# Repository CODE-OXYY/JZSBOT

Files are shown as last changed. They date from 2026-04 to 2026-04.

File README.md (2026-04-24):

# JZSBOT (Desktop Pet Robot)
I built a custom desktop robot with the personality of my favorite streamer, including audio and animation which are stored in sd card. It was built entirely from scratch, I designed both the custom electronics (PCB) and the physical 3D body (CAD) it can move with the help of two N20 motors, show animations on a 3.5 inch display which is the face of the robot, and play sound with the help of a 3 ohm 4 watt speaker. This robot has built in environment, gyro, and other sensors.

## 🛠️ Hardware & PCB Design
The schematic was designed in Altium, split into 3 sheets for better readability.

### Schematics
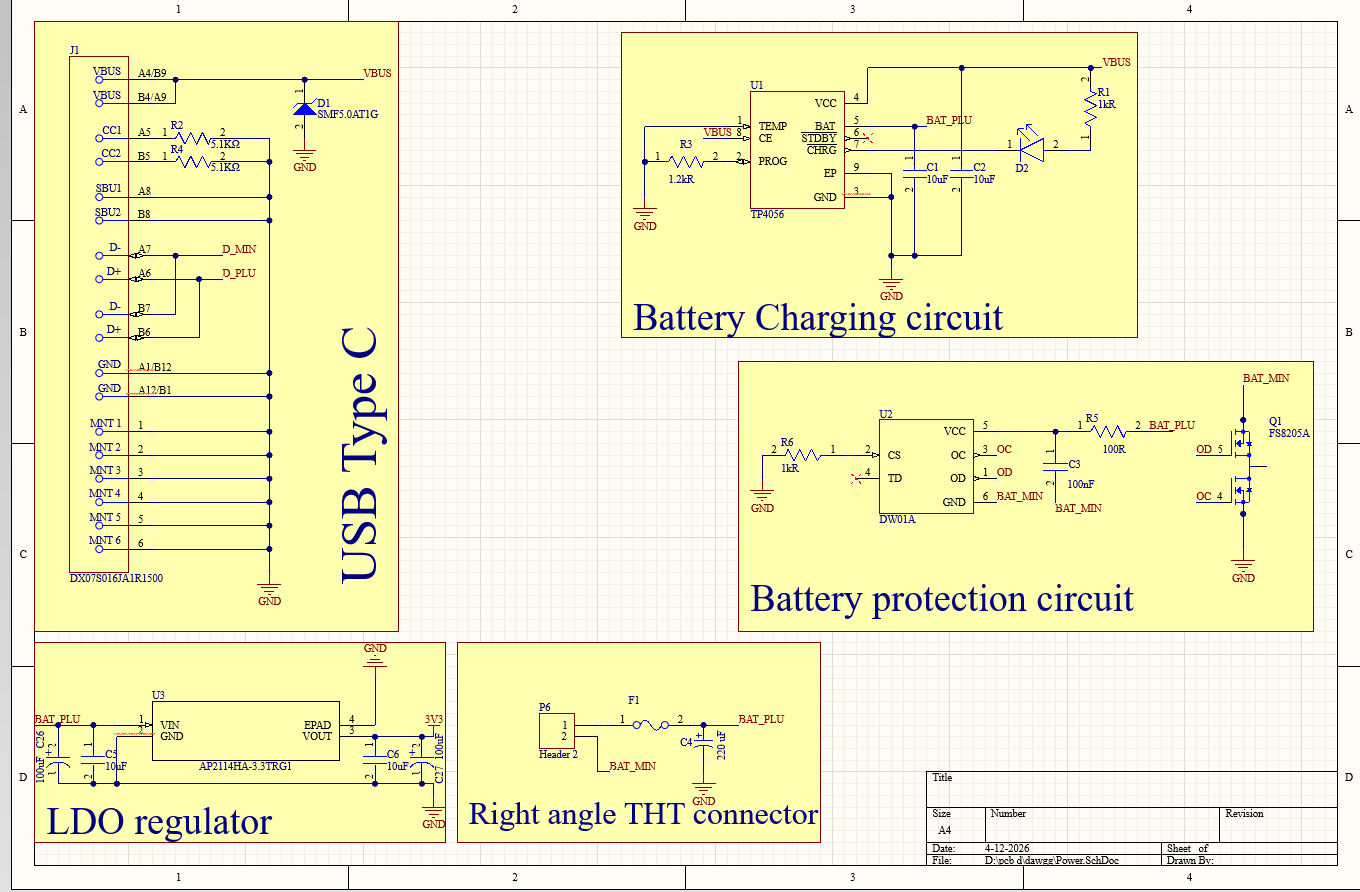
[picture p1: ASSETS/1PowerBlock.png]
Power Section

*Sheet 1: Power Section*

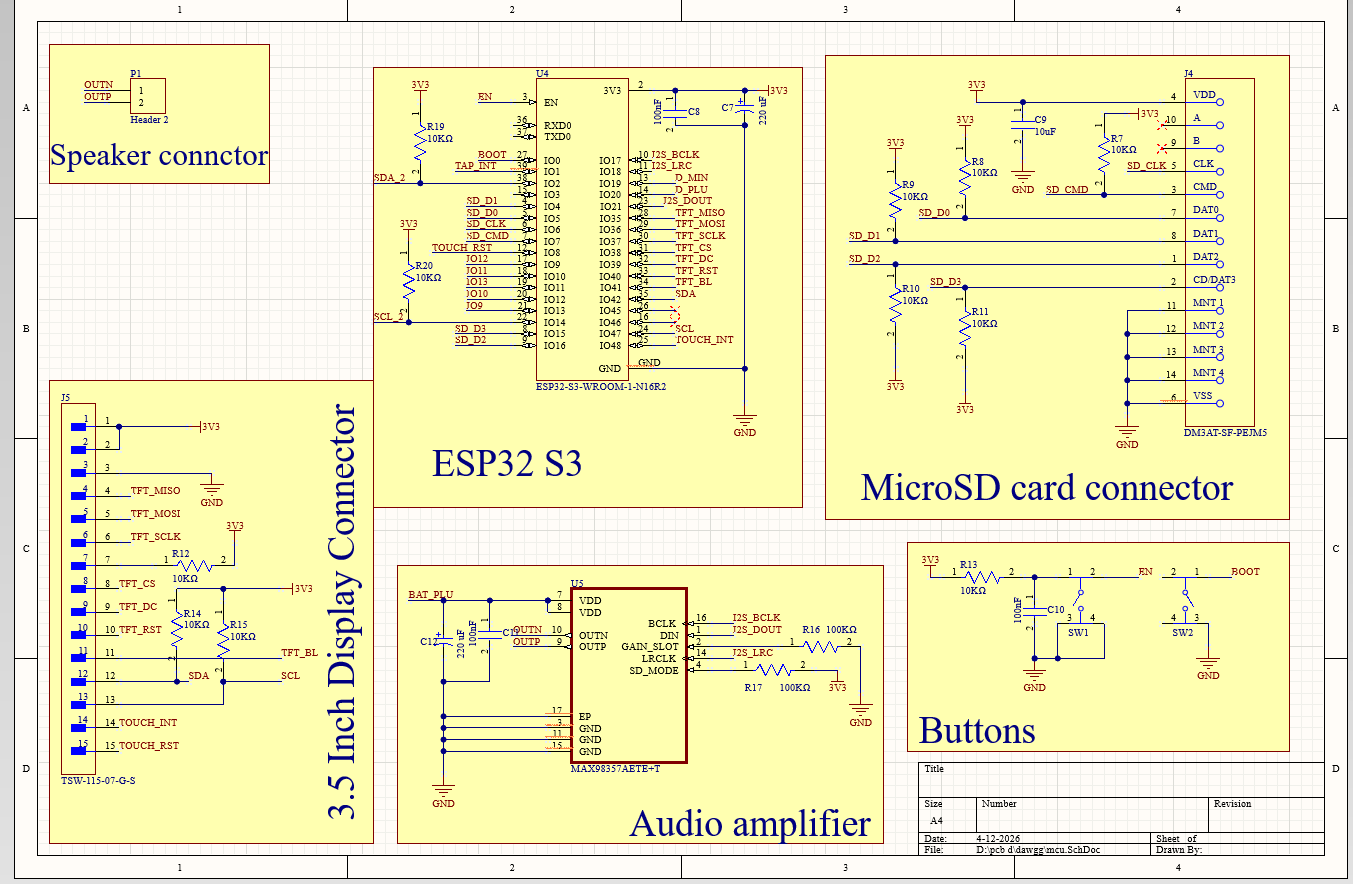
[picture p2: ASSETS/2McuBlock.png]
MCU Section

*Sheet 2: MCU Section*

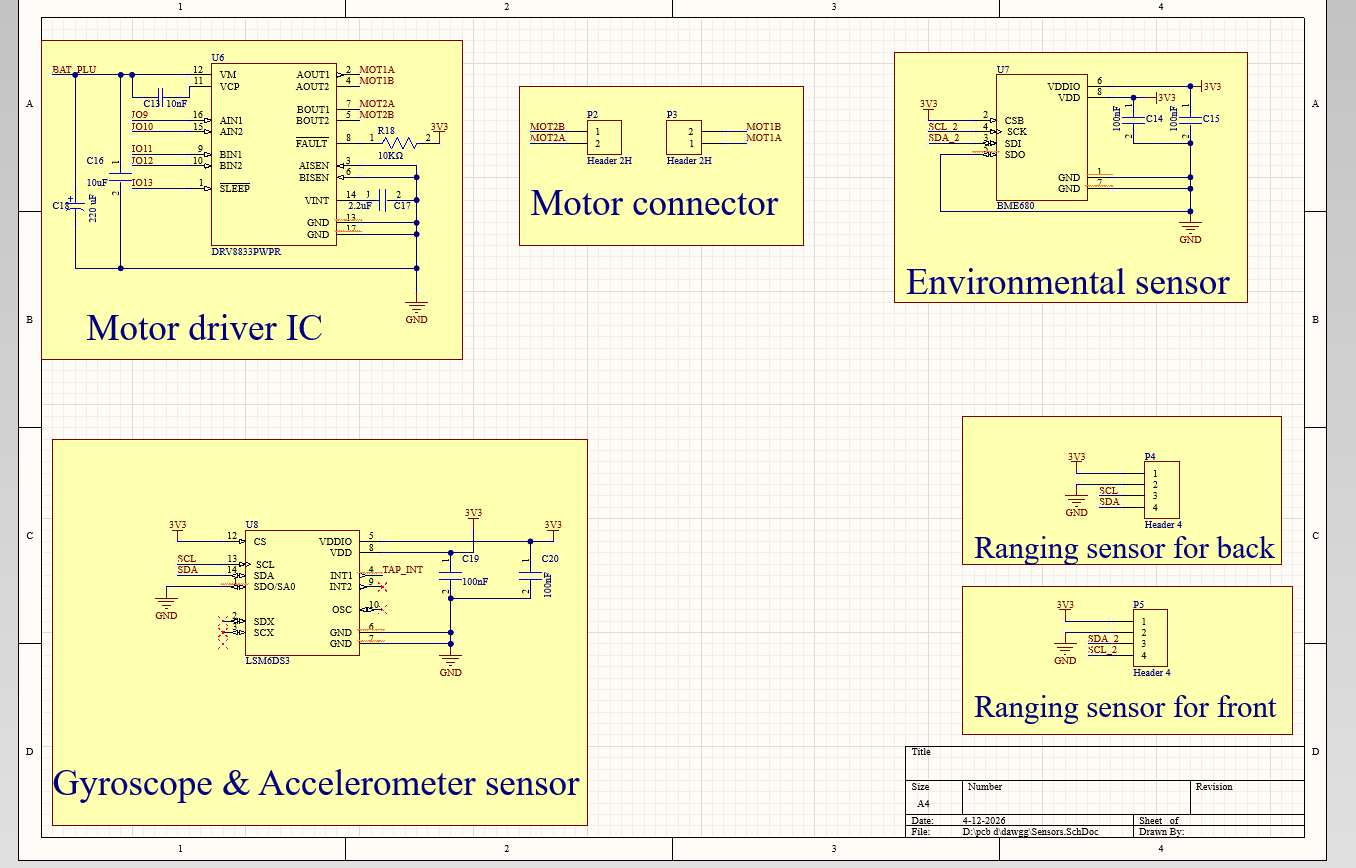
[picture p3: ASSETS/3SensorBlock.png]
Sensor Section

*Sheet 3: Sensor Section*

### PCB Layout
Designed at a precise 84mm x 83mm, keeping it under the cheap 100x100mm manufacturing threshold.
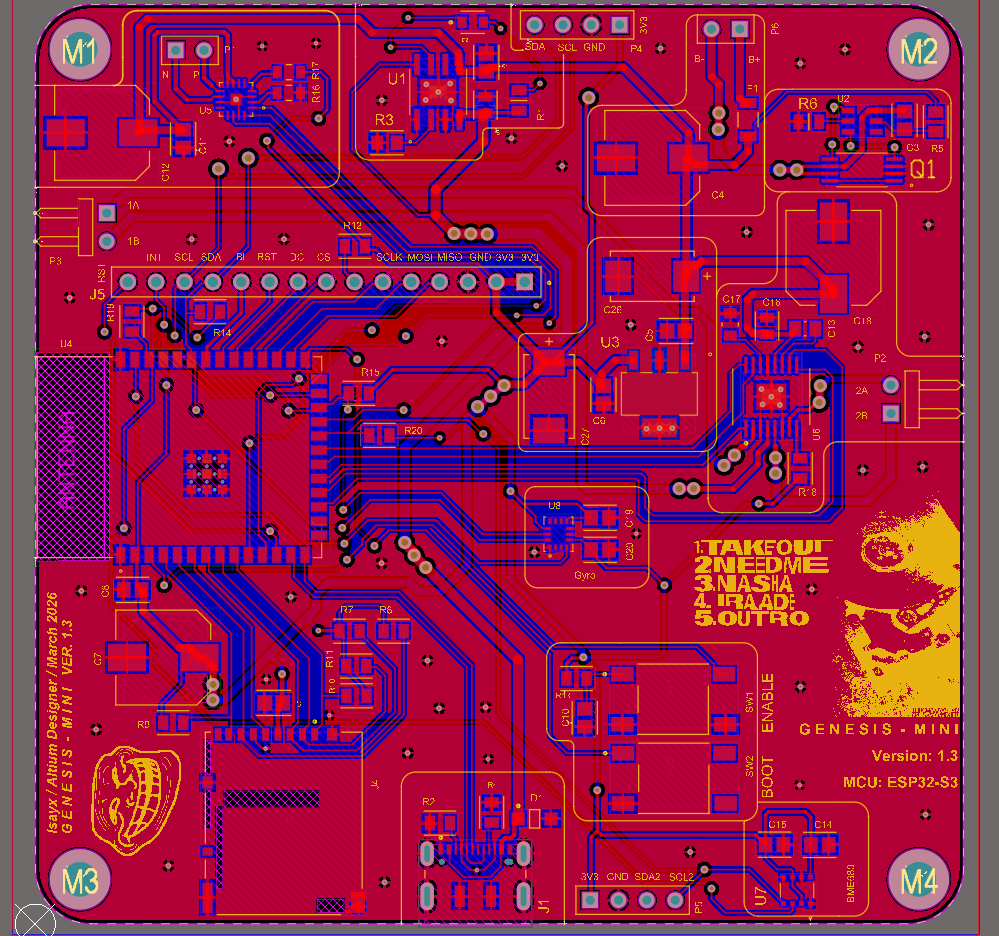
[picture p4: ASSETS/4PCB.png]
PCB Layout


### PCB 3D View
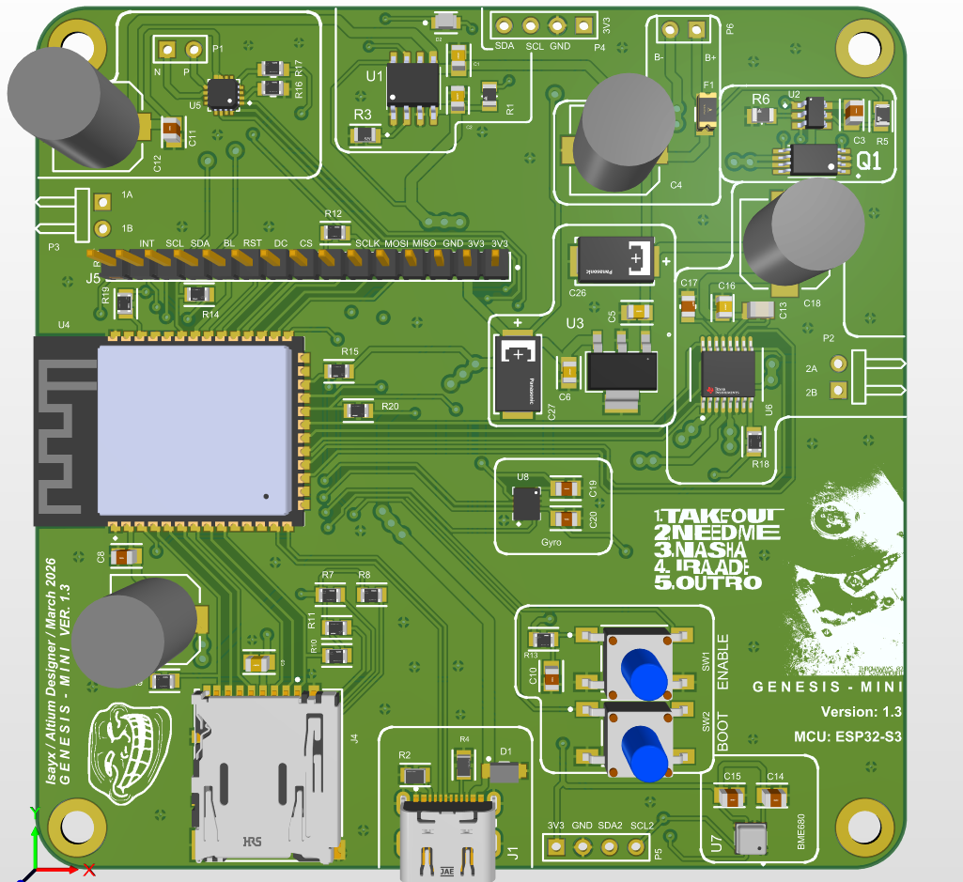
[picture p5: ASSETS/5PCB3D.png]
PCB 3D


---

## 📦 Mechanical Design (Body)
The custom enclosure was modeled in **Onshape** and is split into 4 main 3D printable parts.
🔗 **[View 3D Model on Onshape](https://cad.onshape.com/documents/115dd9a062e470791892991f/w/46b9cbcaef62df69c897060a/e/b46bb490fd50a7f6dd43c250)**

### Head Cap
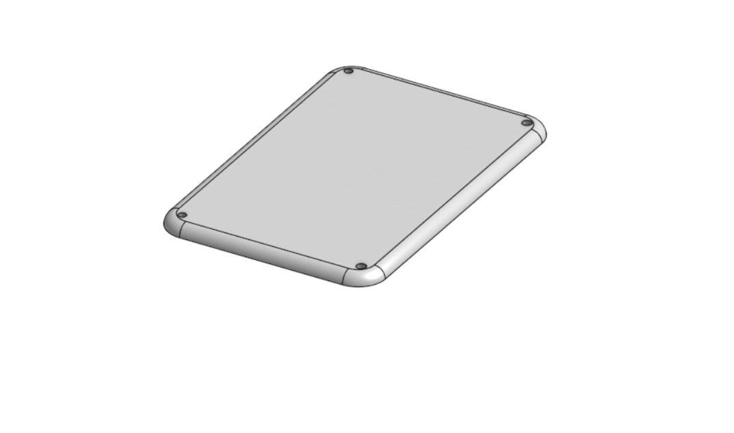
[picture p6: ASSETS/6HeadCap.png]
Head Cap


### Head
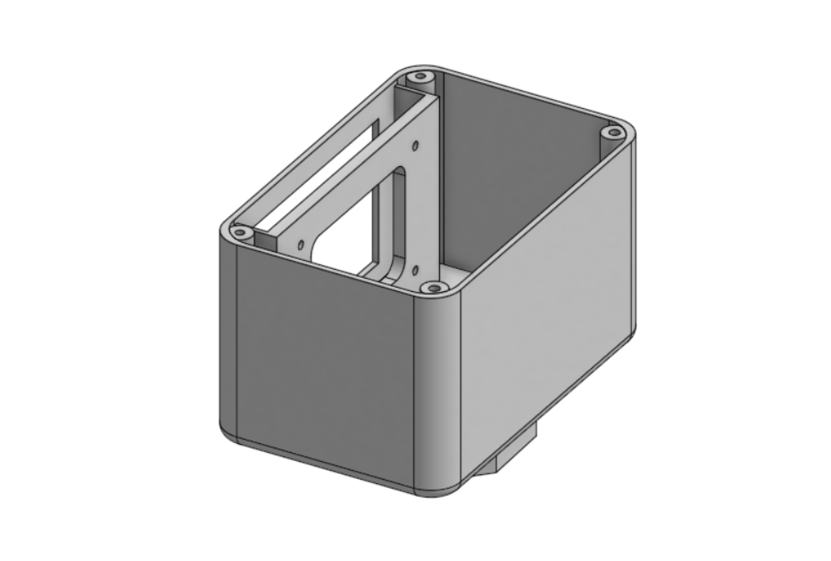
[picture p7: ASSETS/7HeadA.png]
Head A

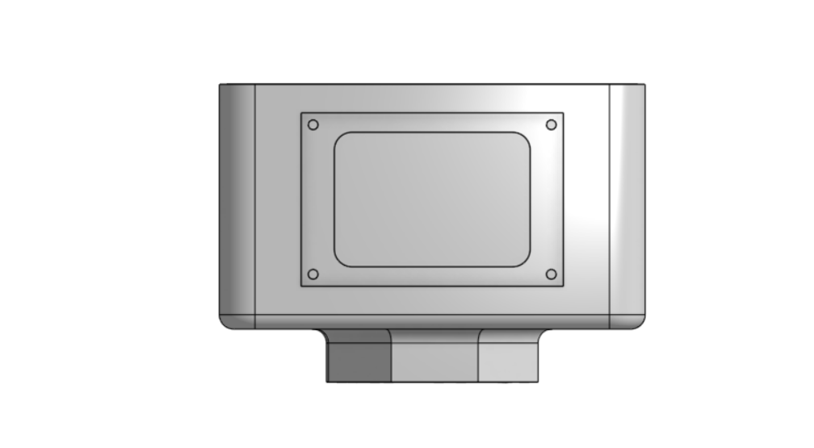
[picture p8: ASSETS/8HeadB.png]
Head B


### Walls
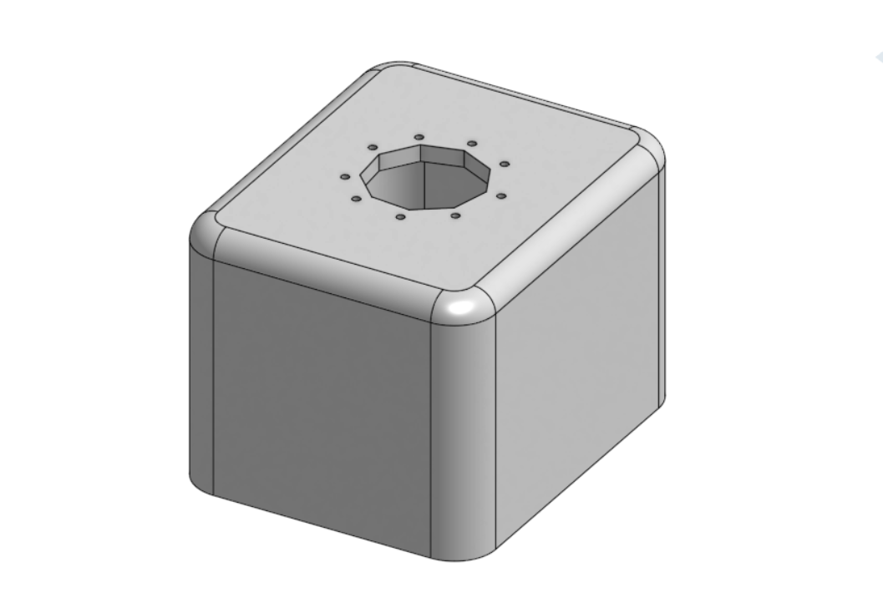
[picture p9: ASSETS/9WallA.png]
Wall A

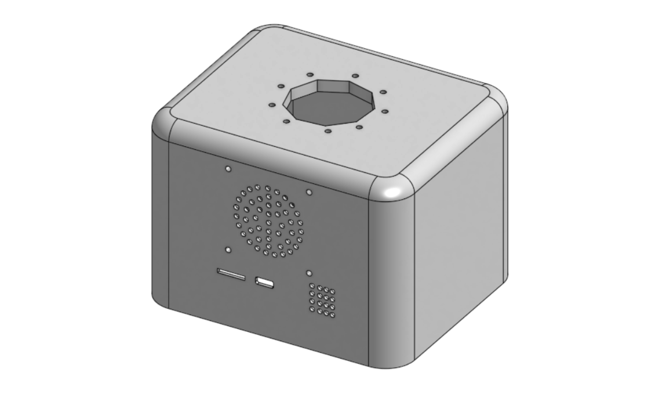
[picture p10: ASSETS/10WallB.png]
Wall B


### Base
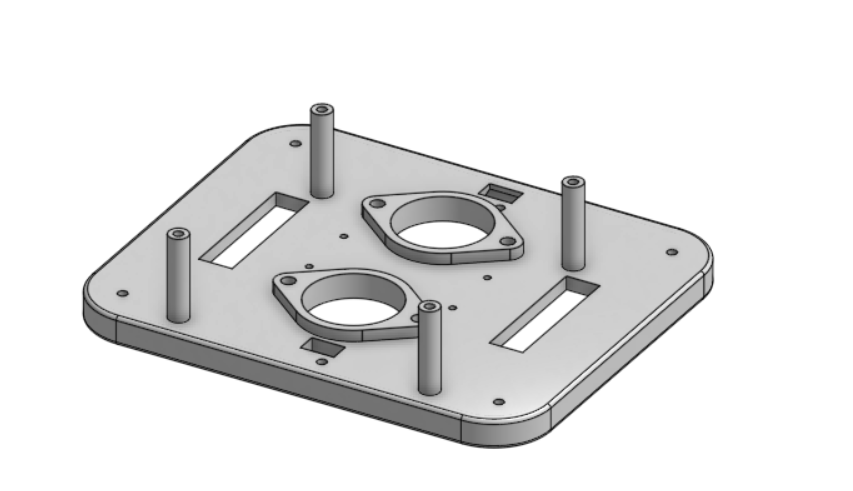
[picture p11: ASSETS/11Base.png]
Base

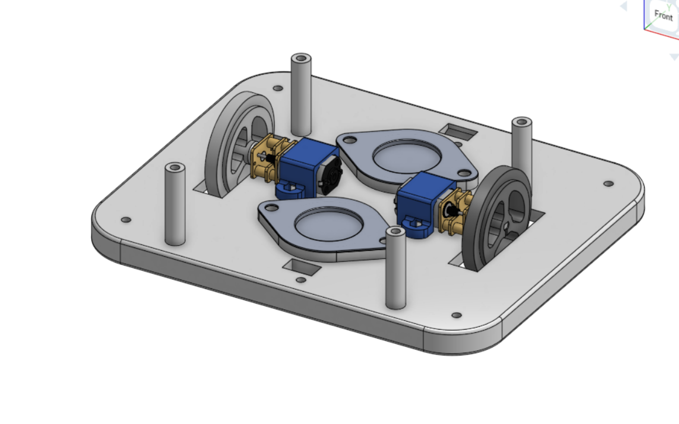
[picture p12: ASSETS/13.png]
Base Details


### Assembly
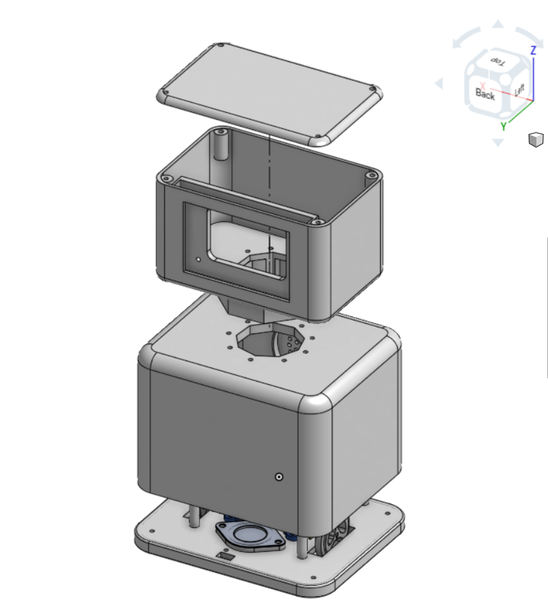
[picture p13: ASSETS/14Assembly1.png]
JZSBOT Assembly 1

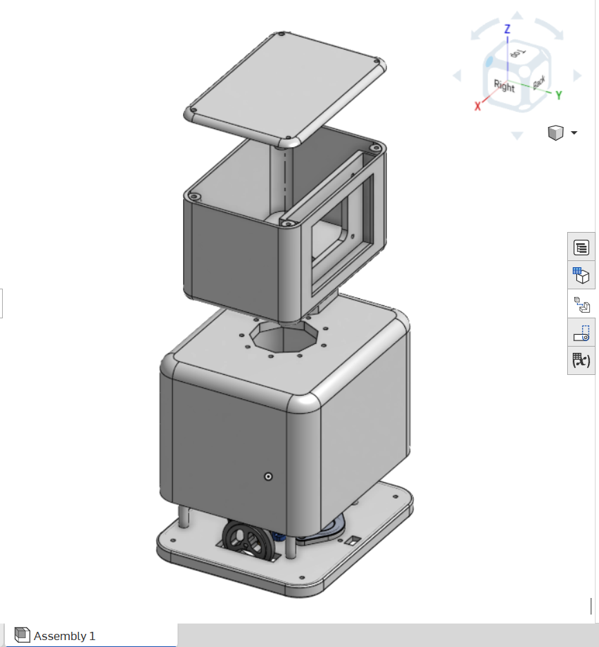
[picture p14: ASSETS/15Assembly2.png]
JZSBOT Assembly 2

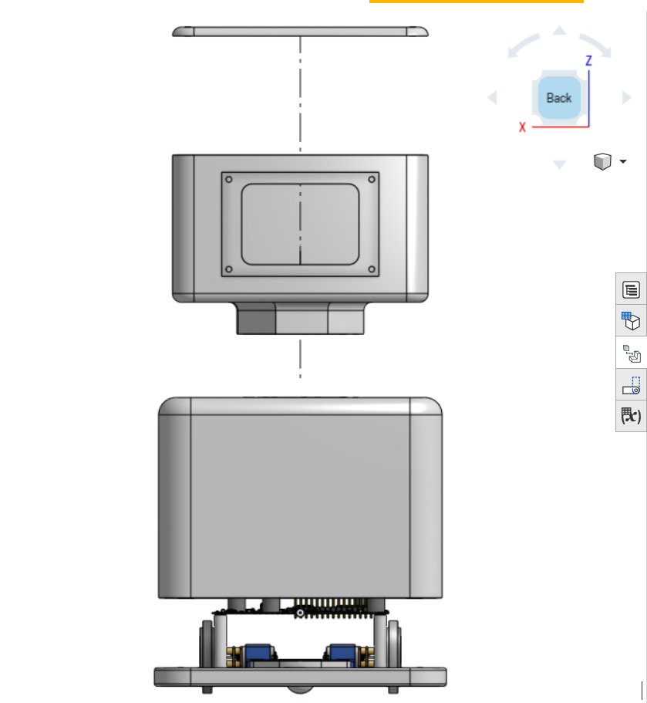
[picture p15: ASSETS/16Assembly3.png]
JZSBOT Assembly 3

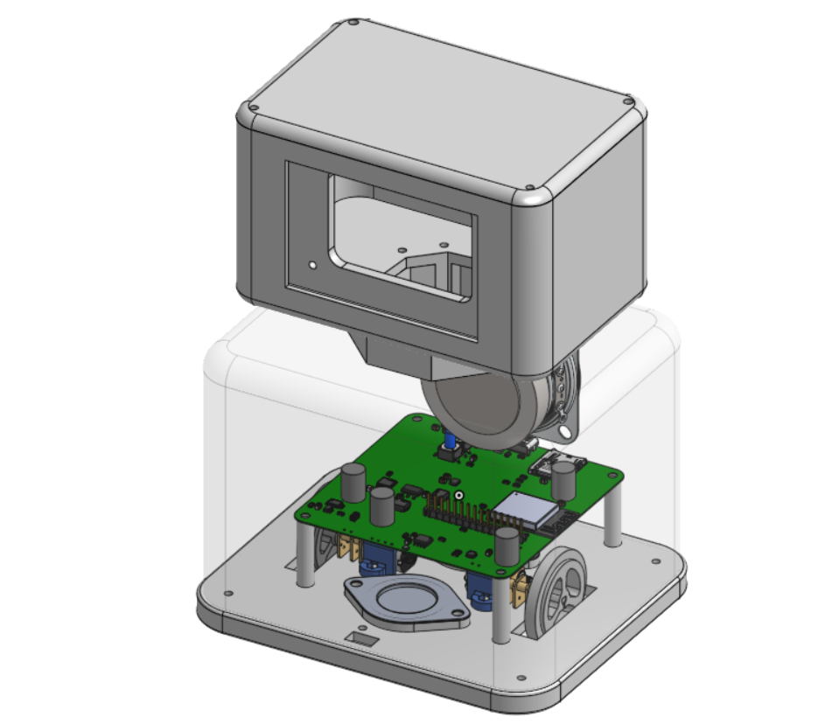
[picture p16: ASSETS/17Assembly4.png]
JZSBOT Assembly 4

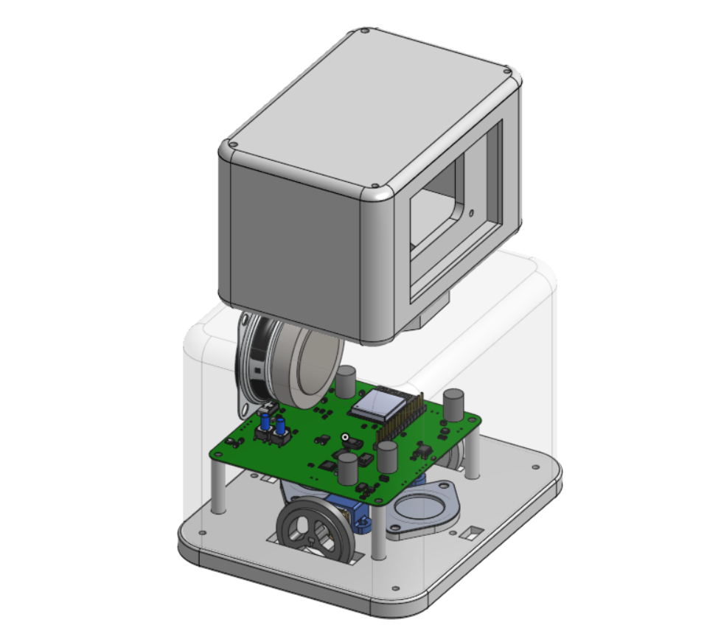
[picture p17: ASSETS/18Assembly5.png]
JZSBOT Assembly 5

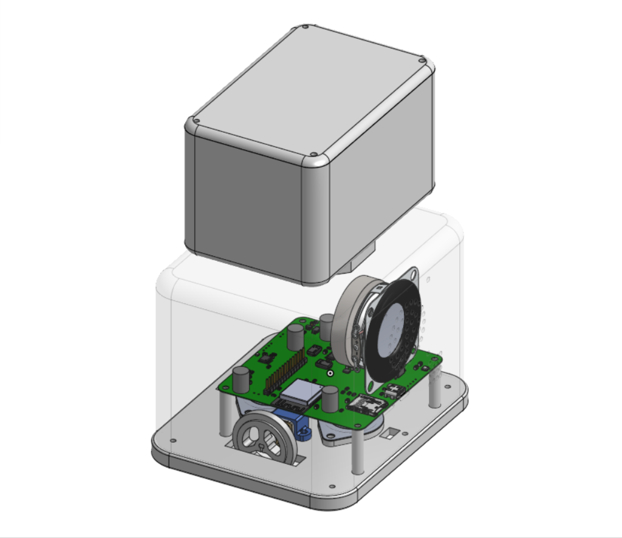
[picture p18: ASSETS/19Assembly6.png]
JZSBOT Assembly 6


### Fully Assembled JZSBOT
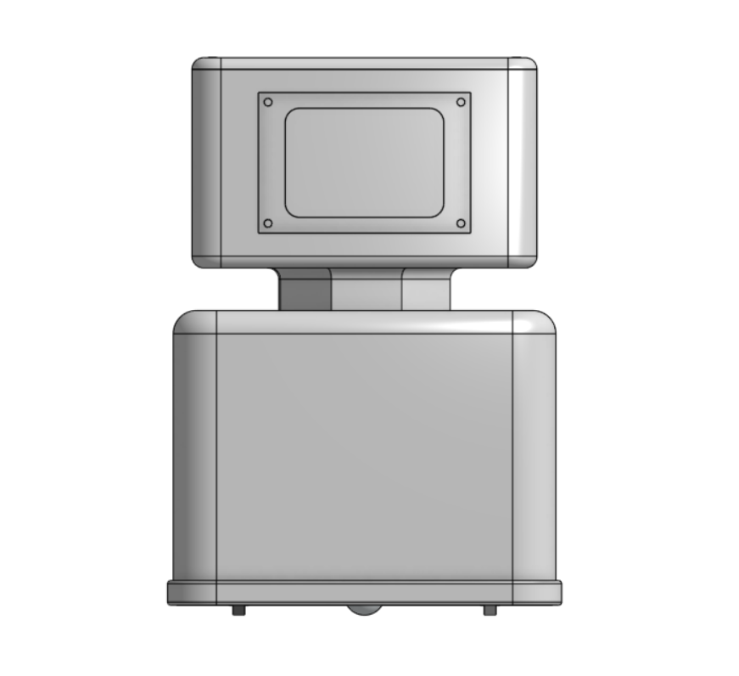
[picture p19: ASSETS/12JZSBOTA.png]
JZSBOT Assembled A

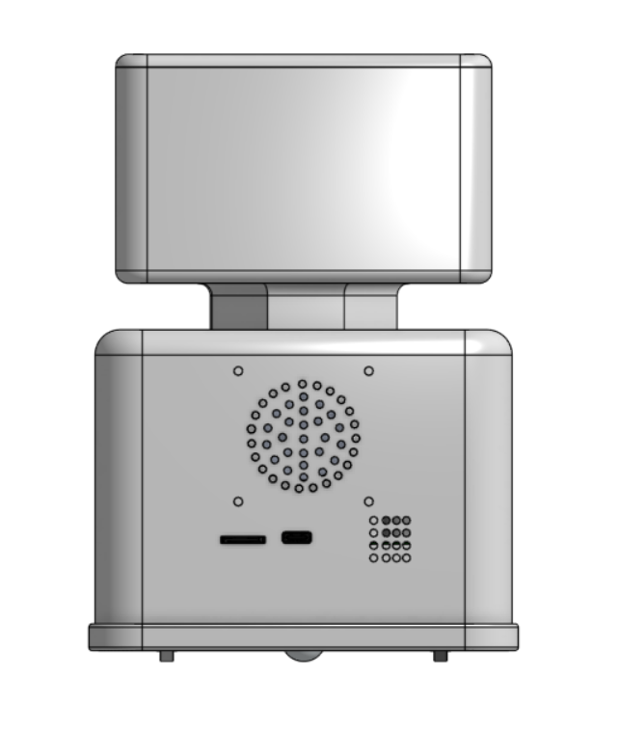
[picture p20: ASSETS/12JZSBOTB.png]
JZSBOT Assembled B

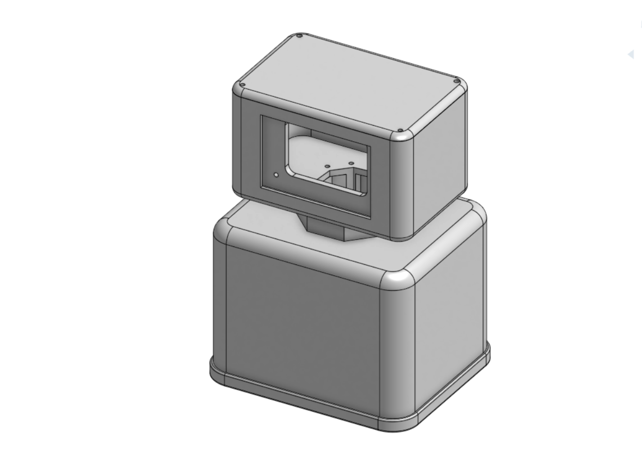
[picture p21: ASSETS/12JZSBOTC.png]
JZSBOT Assembled C


---

## ✨ Features
* **Brain:** ESP32-S3
* **Face:** 3.5" Waveshare Capacitive Touch Display
* **Audio:** On-board 4 ohm 3W speaker for personality sounds
* **Sensors:** BME680 (Environment), LSM6DS3 (Accelerometer & Gyroscopes) and VL53L0X (Distance)
* **Movement:** 2x N20 Motors with a middle drive layout and front/back ball casters for a floating and zero turn feel
* **Firmware:** C/C++

---

## 🛒 Bill of Materials (Hardware Needed)

* **1x** 3.5" Waveshare Capacitive Touch Display
* **1x** 4-ohm 3W Speaker
* **2x** N20 Micro Gear Motors 
* **2x** 34mm Wheels
* **1x** jumper wires
* **2x** Ball Caster Wheels
* **1x** Li-ion Battery
* **2x** VL53L0X Laser Ranging Sensor
* **1x** Custom PCBA
* Assorted M3 Screws, Nuts & Washers (for mounting display,speaker & connecting parts together)
* 3D Printed Parts (Base, Wall, Head, Head Cap)

## ✨ PCBA Parameters

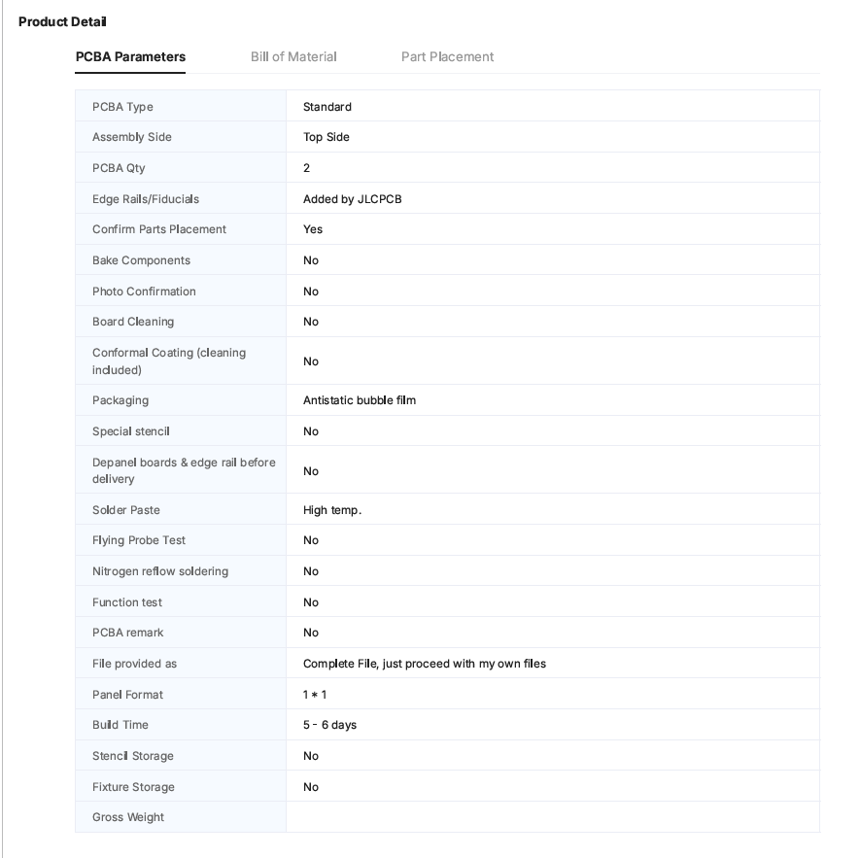
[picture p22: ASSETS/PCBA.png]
PCBA Parameters


---

### Extra stuff
**JZS SZN 2025 THEY KNOW IM COMING**

## 📄 License
This project is open-source and available under the **MIT License**.

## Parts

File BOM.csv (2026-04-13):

Product Name | Quanity | Total Price | Notes | Link
PCBA | 5 | $148.00 | 5 PCB with 2 PCBA | JLC PCB
N20 motar | 2 | $5.84 | out of stock for now will be back in a week | https://robu.in/product/n20-3v-100-rpm-micro-metal-gear-box-dc-motor-copy-2/
Ball Caster Wheel | 2 | $1.20 | out of stock for now will be back in a week | https://robu.in/product/wheel-of-metal/
3.5 inch capacitive touch display | 1 | $21.42 | couldn't find any better alternate | https://robu.in/product/capacitive-touch-display-module/?gad_campaignid=17416544847
Power Wheel | 2 | $1.07 | 34mm in diameter | https://robu.in/product/34mm-mini-car-n20-motor-wheel-rubber-small-wheel/
Ohm 3W FullSpeaker | 1 | $1.28 |  | https://www.amazon.in/product-reviews/B0CSPP3HYH?filterByStar=one_star&reviewerType=all_reviews
jumper wires | 1 | $1.43 | to connect display/laser sensor with main pcb | https://robu.in/product/20-cm-40-pin-dupont-male-male-male-female-female-female-cable-combo/
VL53L0X | 2 | $2.45 |  | https://robu.in/product/vl53l0x-tof-based-lidar-laser-distance-sensor/
M3 20mm Bolt and Nut | 2 | $1.68 | to connect parts together | https://robu.in/product/easymech-m3-x-20mm-chhd-bolt-nut-and-washer-set-20-pcs/
Battery | 1 | $5.36 |  | https://robu.in/product/1s2p-li-ion-battery-pack-2/
Motar Bracket | 2 | $0 | own | own
3d Printed Parts | 4 |  | no idea | Printing Legion

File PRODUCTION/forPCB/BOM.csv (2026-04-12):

Comment | Description | Designator | Footprint | LibRef | Quantity | LCSC Part
SML-LXT0805IW-TR | LED RED DIFFUSED SMD | D2 | FP-SML-LXT0805IW-TR-MFG | CMP-1724-00002-2 | 1 | C2297
10TPC100M | Molded Tantalum Polymer Capacitor 100uF 20% 10V life 2000Hours SMD 2917 | C26, C27 | FP-POSCAP-D2-MFG | CMP-05428-000328-1 | 2 | C7222
C0805C106J8RACAUTO | CAP CER 10UF 10V X7R 0805 | C1, C5, C6, C9 | FP-C0805C106J8RACAUTO-IPC_B | CMP-03020-034708-1 | 4 | C15850
C0805C106J8RACAUTO | CAP CER 10UF 10V X7R 0805 | C2, C16 | FP-C0805C106J8RACAUTO-MFG | CMP-03020-034708-1 | 2 | C15850
TP4056 | Complete single cell Li-Ion battery with a constant current / constant voltage linear charger | U1 | SOP127P600X175-9N | TP4056 | 1 | C16581
RMCF0805JG1K20 | 1.2kO ±5% 0.125W 0805 Thick Film Chip Resistor AEC-Q200 compliant | R3 | FP-RMCF0805-IPC_B | CMP-26527-005543-1 | 1 | C17379
CRCW0805100RJNEAHP | RES Thick Film, 100O, 5%, 0.5W, 200ppm/°C, 0805 | R5 | FP-CRCW0805-HPe3-IPC_B | CMP-02407-002130-1 | 1 | C17408
RT0805FRD0710KL | RES SMD 10K OHM 1% 1/8W 0805 | R7, R8, R9, R10, R11, R12, R13, R14, R15, R18, R19, R20 | FP-RT0805-IPC_B | CMP-03412-035478-1 | 12 | C17414
MCU0805MD1001BP100 | RES 1.05K OHM 0.5% 1/5W 0805 | R1, R6 | FP-MCU0805-IPC_B | CMP-02407-000288-1 | 2 | C17513
RT0805DRD07100KL | RES SMD 100K OHM 0.5% 1/8W 0805 | R16, R17 | FP-RT0805-MFG | CMP-2001-01780-2 | 2 | C25611
AC0805JR-075K1L | RES SMD 5.1K OHM 5% 1/8W 0805 | R2, R4 | FP-AC0805-IPC_B | CMP-2001-04477-2 | 2 | C27834
CC0805KKX7RYBB104 | CC0805KKX7RYBB104 Capacitor Ceramic 0.01uF 250V X7R 10% 0805 T/R | C3, C8, C10, C11, C14, C15, C19, C20 | FP-CC0805-EB-IPC_B | CMP-00621-107850848-1 | 8 | C28233
DRV8833PWPR | IC MOTOR DRIVER PAR 16HTSSOP | U6 | FP-PWP0016C-IPC_B | CMP-1529-00004-3 | 1 | C50506
DM3AT-SF-PEJM5 | CONN MICRO SD CARD PUSH-PUSH R/A | J4 | FP-DM3AT-SF-PEJM5-MFG | CMP-2000-05150-2 | 1 | C114218
BME680 | Gas, Humidity, Pressure, Temperature Sensor I2C, SPI Output | U7 | PSON80P300X300X100-8N | BME680 | 1 | C125972
MF-NSMF200-2 | PTC RESET FUSE 6V 2A 1206 | F1 | FP-MF-NSMF200-2-MFG | CMP-07400-000004-1 | 1 | C269120
08053C225K4Z2A | CAP CER 2.2UF 25V X7R 0805 | C17 | FP-0805-L_2_01_0_2-W_1_25-MFG | CMP-04427-000048-1 | 1 | C377773
CAP 10nF 50V 0805(2012) | CAP 10nF 50V ±10% 0805 (2012 Metric) Thickness 1.45mm SMD | C13 | CAPC0805(2012)145_N | CMP-1036-03843-1 | 1 | C377773
AP2114HA-3.3TRG1 | Description | U3 | SOT-223_DIO | AP2114HA-3.3TRG1 | 1 | C460314
2-1977223-2 | SWITCH TACTILE SPST-NO 0.05A 24V | SW1, SW2 | FP-2-1977223-2-MFG | CMP-03407-000026-1 | 2 | C557615
MAX98357AETE+T | Tiny, Low-Cost, PCM Class D Amplifier with Class AB Performance | U5 | QFN50P300X300X80-17N | MAX98357AETE+T | 1 | C910544
UUD1V221MNL1GS | Aluminum Electrolytic Capacitor, UD Series, Low Impedance, 220 uF, 35 V, + / - 20%, -55 to 105 degC, Chip Type, 8 x 10 mm D x L, Pb-Free, Reel | C4, C7, C12, C18 | NIC-CAPA2-8X10_V | CMP-0687-00080-1 | 4 | C2836441
SMF5.0AT1G | 200 W Transient Voltage Suppressor, 2-Pin SOD-123FL, Pb-Free, Tape and Reel | D1 | ONSC-SOD-123FL-2-498_V | CMP-1061-00612-1 | 1 | C2857263
ESP32-S3-WROOM-1-N16R2 | Bluetooth, WiFi 802.11b/g/n, Bluetooth v5.0 Transceiver Module 2.4GHz PCB Trace Surface Mount | U4 | XCVR_ESP32-S3-WROOM-1-N16R2 | ESP32-S3-WROOM-1-N16R2 | 1 | C2913205
TSW-115-07-G-S | CONN HEADER VERT 15POS 2.54MM | J5 | FP-TSW-115-07-G-S-MFG | CMP-02766-000090-1 | 1 | C2932704
DX07S016JA1R1500 | CONN RCP USB2.0 TYP C 24P SMD RA | J1 | FP-DX07S016JA1R1500-MFG | CMP-19038-000003-1 | 1 | C3197885
FS8205A |  | Q1 | SOP65P640X120-8N | FS8205A | 1 | C5148694
DW01A | One Cell Lithium-ion/Polymer Battery Protection IC | U2 | SOT95P280X145-6N | DW01A | 1 | C18164398
Header 2H | Header, 2-Pin, Right Angle | P2, P3 | HDR1X2H | Header 2H | 2 | C32713261
Header 2 | Header, 2-Pin | P1, P6 | HDR1X2 | Header 2 | 2 | C32713268
Header 4 | Header, 4-Pin | P4, P5 | HDR1X4 | Header 4 | 2 | C42431787
LSM6DS3 | Accelerometer, Gyroscope, Temperature, 6 Axis Sensor IÂ²C, SPI Output | U8 | PQFN50P300X250X86-14N | LSM6DS3 | 1 | LSM6DS3TR-C

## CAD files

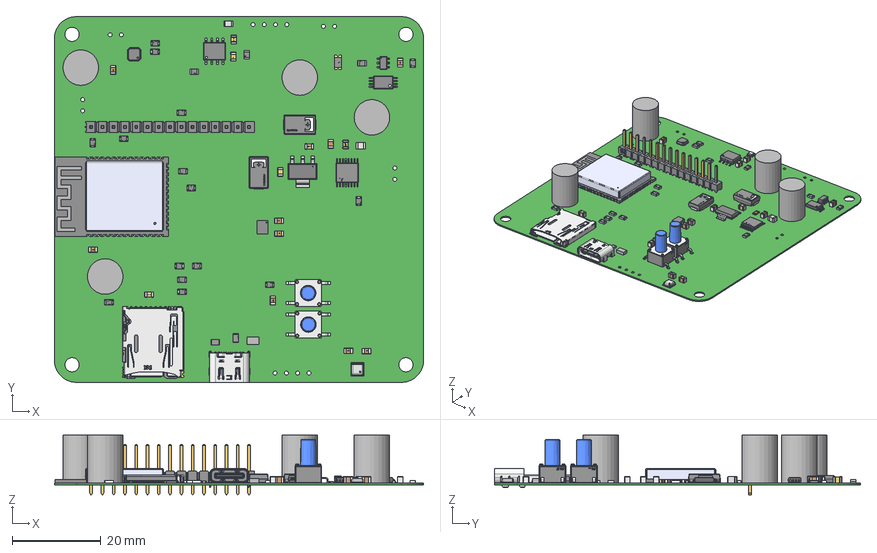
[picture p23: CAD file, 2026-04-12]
PCB/PCB1.step
83.2 x 82.4 x 13.5 mm
pins x 14
logo x 17
JAE
DM3AT-SF-PEJM5
Hirose Logo adjastable
Extruded x 6
Texas Logo Yury
Texas Logo Yury - Copy
Base x 2
Steel Cover x 2
notch x 2
Actuator x 2
Leads x 2
TE x 2
terminals x 3
top x 3
Vishay CRCW08053R00FKEAHP
Pieza18
Pieza26
Pieza27
_TSW-115-07-G-S_body
_T-1S6-07-TSW-1-07-15-S
Samtec Logo x 2
Samtec Logo - 1 x 2
side x 16
Yageo Logo x 8
AVX_Logo
KEMET x 6

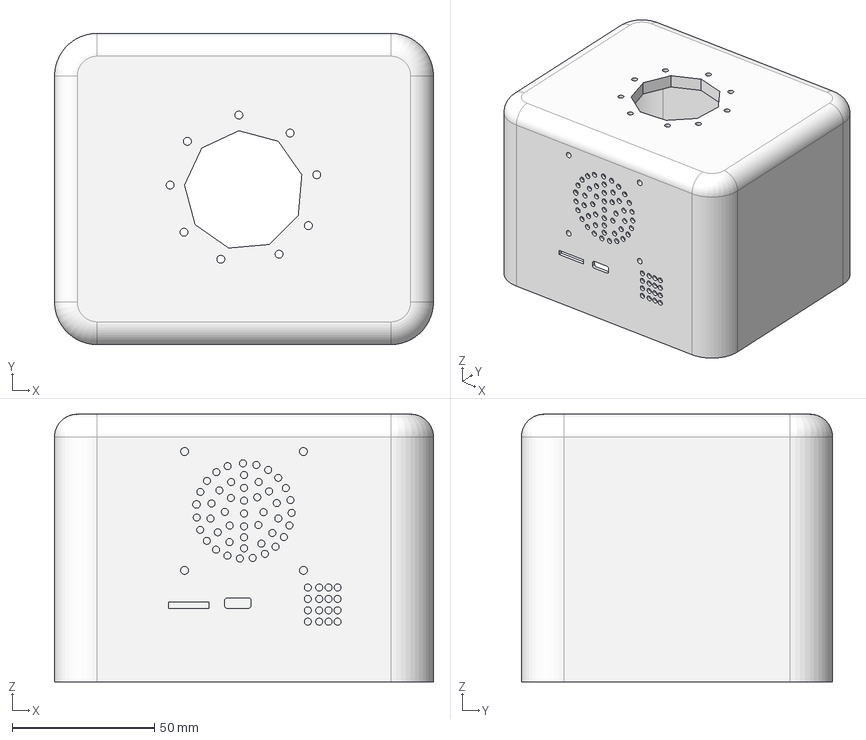
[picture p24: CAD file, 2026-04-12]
PRODUCTION/forCAD/3Wall.step
133.1 x 109.3 x 94.0 mm

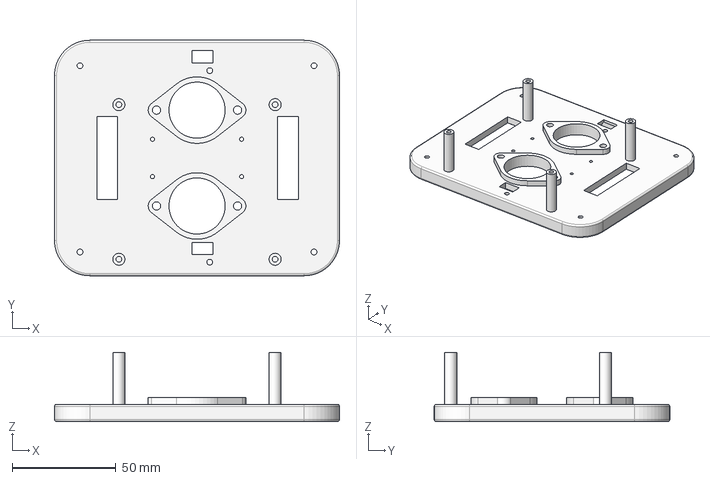
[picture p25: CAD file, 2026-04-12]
PRODUCTION/forCAD/4Base.step
137.1 x 113.3 x 33.4 mm

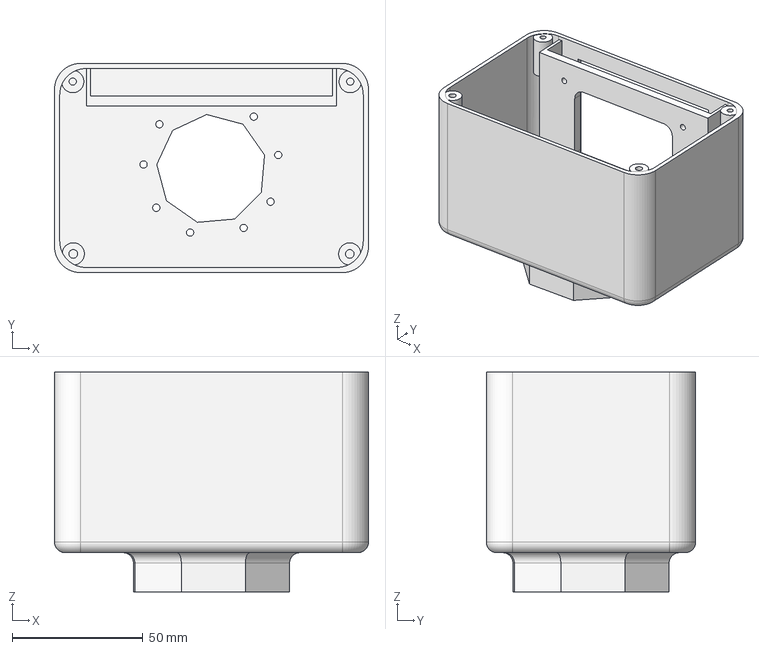
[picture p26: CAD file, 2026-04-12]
PRODUCTION/forCAD/2Head.step
120.0 x 80.0 x 84.0 mm

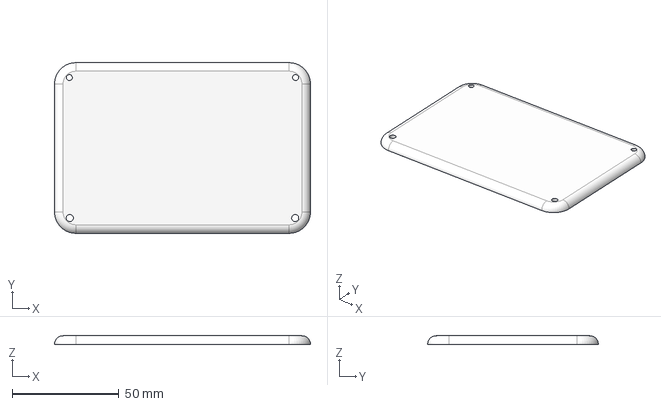
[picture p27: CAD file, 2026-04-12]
PRODUCTION/forCAD/1HeadCap.step
120.0 x 80.0 x 4.00 mm

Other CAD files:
PRODUCTION/forCAD/1HeadCap.stl
PRODUCTION/forCAD/2Head.stl
PRODUCTION/forCAD/3Wall.stl
PRODUCTION/forCAD/4Base.stl

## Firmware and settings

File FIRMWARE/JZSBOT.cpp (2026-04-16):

#include <Wire.h>
#include <Adafruit_Sensor.h>
#include <Adafruit_LSM6DS33.h> 
#include <Adafruit_BME680.h>
#include <Adafruit_VL53L0X.h>
#include <TFT_eSPI.h>          
#include <driver/i2s.h>        

// PINS
#define I2C1_SDA 35   // SDA1
#define I2C1_SCL 36   // SCL1
#define I2C2_SDA 2    // SDA2
#define I2C2_SCL 13   // SCL2

//  Motor Driver
#define motA1 9
#define motA2 10
#define motB1 11
#define motB2 12
#define motSleep 13  

// I2S Speaker
#define I2C_BCLK  48
#define I2S_LRC   21
#define I2S_DOUT  47


Adafruit_LSM6DS33 lsm;
Adafruit_BME680 bme; 
Adafruit_VL53L0X laser_back = Adafruit_VL53L0X();  
Adafruit_VL53L0X laser_front = Adafruit_VL53L0X(); 
TFT_eSPI tft = TFT_eSPI(); 
unsigned long lastReadTime = 0;

void setup() {
  Serial.begin(115200);
  while (!Serial) delay(10);
  Serial.println("\n--- JZSBOT STARTTTTTTTTTT ---");

  //  DISPLAY
  tft.init();
  tft.setRotation(1); 
  tft.fillScreen(TFT_BLACK);
  tft.setTextColor(TFT_WHITE);
  tft.drawString("JZSBOT NOW I AM COMING", 10, 10, 4);
  Serial.println("FACE Initialized");

  // MOTOR 
  pinMode(motA1, OUTPUT);
  pinMode(motA2, OUTPUT);
  pinMode(motB1, OUTPUT);
  pinMode(motB2, OUTPUT);
  pinMode(motSleep, OUTPUT);
  digitalWrite(motSleep, HIGH); 
  Serial.println("LEGS Initialized !!!!!");

  // DUAL I2C  SETUP
  Wire.begin(I2C1_SDA, I2C1_SCL);        
  Wire1.begin(I2C2_SDA, I2C2_SCL);       

  // LSM6DS3 
  if (!lsm.begin_I2C(0x6A, &Wire)) { 
    Serial.println("LSM6DS3 Not Found :( ");
    tft.drawString("RIP LSM6DS3 KABOOM", 10, 40, 2);
  } else {
    Serial.println("LSM6DS3 Found :)");
    tft.drawString("LSM6DS3 Is Happyyy", 10, 40, 2);
  }

  // BME680 
  if (!bme.begin(0x76, &Wire)) { 
    Serial.println(" BME680 Not Found :( ");
    tft.drawString(" RIP BME680 KABOOM ", 10, 60, 2);
  } else {
    Serial.println(" BME680 Found :) ");
    tft.drawString("BME680 Is Happyyy ", 10, 60, 2);
    bme.setTemperatureOversampling(BME680_OS_8X);
    bme.setHumidityOversampling(BME680_OS_2X);
    bme.setPressureOversampling(BME680_OS_4X);
    bme.setIIRFilterSize(BME680_FILTER_SIZE_3);
    bme.setGasHeater(320, 150); 
  }

   //  LASER (VL53L0X)
  if (!laser_back.begin(0x29, false, &Wire, Adafruit_VL53L0X::VL53L0X_SENSE_DEFAULT)) {
    Serial.println("Laser Back Not Found :( ");
  } else {
    Serial.println("Laser Back Found :) ");
  }

  if (!laser_front.begin(0x29, false, &Wire1, Adafruit_VL53L0X::VL53L0X_SENSE_DEFAULT)) {
    Serial.println(" Laser Front Not Found :( ");
  } else {
    Serial.println("Laser Front Found :)");
  }

   // AUDIO
  i2s_config_t i2s_config = {
   .mode = (i2s_mode_t)(I2S_MODE_MASTER | I2S_MODE_TX),
   .sample_rate = 44100,
   .bits_per_sample = I2S_BITS_PER_SAMPLE_16BIT,
   .channel_format = I2S_CHANNEL_FMT_ONLY_LEFT,
   .communication_format = I2S_COMM_FORMAT_STAND_I2S,
   .intr_alloc_flags = ESP_INTR_FLAG_LEVEL1,
   .dma_buf_count = 8,
   .dma_buf_len = 64,
   .use_apll = false
  };
  i2s_pin_config_t pin_config = {
   .bck_io_num = I2C_BCLK,
   .ws_io_num = I2S_LRC,
   .data_out_num = I2S_DOUT,
   .data_in_num = I2S_PIN_NO_CHANGE
  };
  i2s_driver_install(I2S_NUM_0, &i2s_config, 0, NULL);
  i2s_set_pin(I2S_NUM_0, &pin_config);
  Serial.println("Audio Initialized HEHEHEHE !!!!");

  Serial.println(" JZS WOKE UP \n");
  delay(2000);
  tft.fillScreen(TFT_BLACK);
}

void loop() {
  if (millis() - lastReadTime > 1000) { 
    lastReadTime = millis();
    
    // READ BME680 Sensor Value
    if (bme.performReading()) {
      Serial.print("Temperature is ");
      Serial.print(bme.temperature);
      Serial.println(" *C");
    }

    // READ LSM6DS3 Values
    sensors_event_t accel, gyro, temp;
    lsm.getEvent(&accel, &gyro, &temp);
    Serial.print("Acceleration: "); 
    Serial.print(accel.acceleration.x); 
    Serial.println(" m/s^2");

    // READ VL53L0X Values
    VL53L0X_RangingMeasurementData_t measure_back;
    laser_back.rangingTest(&measure_back, false);
    if (measure_back.RangeStatus!= 4) {
      Serial.print("Above Surface Back: "); 
      Serial.print(measure_back.RangeMilliMeter); 
      Serial.println(" mm");
    }
    
    VL53L0X_RangingMeasurementData_t measure_front;
    laser_front.rangingTest(&measure_front, false);
    if (measure_front.RangeStatus!= 4) {
      Serial.print("Above Surface Front: "); 
      Serial.print(measure_front.RangeMilliMeter); 
      Serial.println(" mm");
    }

    Serial.println("========= HIIIIIIIIIIIIIII =======\n");
  }

  motarTest(); 
}

void motarTest() {
  // Move forward
  digitalWrite(motA1, HIGH); 
  digitalWrite(motA2, LOW);

  digitalWrite(motB1, HIGH); 
  digitalWrite(motB2, LOW);
  delay(1000);

  // Stopppp
  digitalWrite(motA1, LOW); 
  digitalWrite(motA2, LOW);

  digitalWrite(motB1, LOW); 
  digitalWrite(motB2, LOW);
  delay(2000);
}

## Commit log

2026-04-24 Addes assembly images
2026-04-24 Added Assembly images
